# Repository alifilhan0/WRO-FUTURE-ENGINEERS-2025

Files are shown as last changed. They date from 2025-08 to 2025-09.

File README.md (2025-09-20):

# WRO Future Engineers 2025 – Team Barakah Brigade

>_"Machines may move, but minds make them meaningful."_

## I. The Chronicle Begins

Welcome to the official documentation of **Team Barakah Brigade**, proudly representing **Bangladesh** in the **WRO Future Engineers 2025** challenge. Our machine is not only a competition entry — it's a product of relentless design, weekend solder burns, deep debugging sessions, and the shared dream of building something that _knows what to do_ when left alone.

## II. The Machine: Purpose, Not Parts

Our vehicle is modular, intelligent, and ever-adapting. It uses a hybrid sensor approach to interpret its surroundings and make autonomous driving decisions in real-time — under the constraints and chaos of a real track.

### Core Concepts:

- **Multi-sensor Fusion**: For reliable perception, redundancy, and adaptation.
- **Real-time RTOS Decision Engine**: Powered by RT-Smart, giving predictable, scheduled execution for safety and speed. Providing an environment 
- **Microcontroller Offload Architecture**: Peripheral-heavy sensor reading offloaded to a C-programmed sensor hub board.
- **PWM-driven Motion**: Real-time speed and torque adjustments via software PWM on hardware-level pins.
- **Visual Processing Backbone**: Using the OV5647 camera as the main eye of the vehicle.
- **Machine Learning assisted motion**: Following the current trends, and picking up with the modern pace, ML assisted motion brings us the edge of driving and transportation technology with automation and reliablity

---
## Table of Contents

- [III. The Team](#iii-the-team)
- [IV. Mechanical Subsystem](#iv-mechanical-subsystem)
  - [Drive Train](#drive-train)
  - [Steering](#steering)
  - [Wheel Base](#wheel-base)
  - [Top and Base](#top-and-base)
  - [Camera Mount](#camera-mount)
- [V. Electrical Subsystem](#v-electrical-subsystem)
  - [Hardware Component Overview](#hardware-component-overview)
  - [CanMV K230 — The Heart of the Project That Brings Everything to Life](#canmv-k230--the-heart-of-the-project-that-brings-everything-to-life)
  - [K230 vs Raspberry Pi: Why We Preferred the K230](#k230-vs-raspberry-pi-why-we-preferred-the-k230)
  - [Custom PCBs](#custom-pcbs)
    - [(A) MCU Carrier Board](#a-mcu-carrier-board)
    - [(B) Power Distribution Board (PDB)](#b-power-distribution-board-pdb)
  - [Sensor Modules & Specifications](#sensor-modules--specifications)
    - [Reasoning behind choosing ToF Over Ultrasonic Sensors](#reasoning-behind-choosing-tof-over-ultrasonic-sensors)
    - [How we tackled problems while sensor calibration and debugging](#how-we-tackled-problems-while-sensor-calibration-and-debugging)
      - [Problem](#problem)
      - [Analysis](#analysis)
      - [Solution and Process](#solution-and-process)
    - [How it works at low level](#how-it-works-at-low-level)
    - [Other Active Modules](#other-active-modules)
      - [TCA9548A](#tca9548a)
      - [16GA 800RPM Motor](#16ga-800rpm-motor)
      - [JX-6221-MGI Servo](#jx-6221-mgi-servo)
- [VI. Software Subsystem](#vi-software-subsystem)
  - [Overview (Open Challenge)](#overview--open-challenge-)
    - [Approach](#approach)
    - [Data Collection](#data-collection)
    - [Model Training](#model-training)
    - [Conclusion](#conclusion)

## III. The Team

| Name | Role | Focus Areas | Picture |
|---|---|---|---|
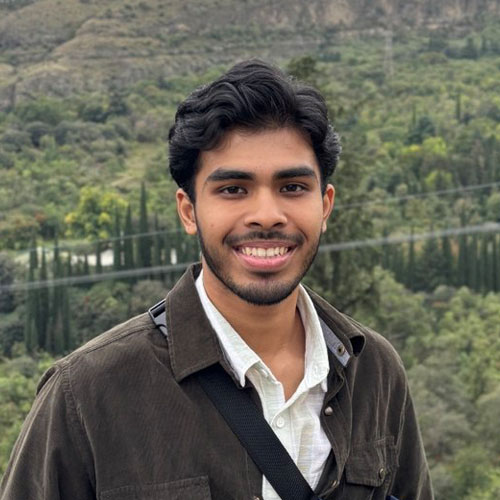
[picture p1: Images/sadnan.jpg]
| **Sadnan Adib Khan**  | Team Lead | Strategy, PCB design, Mechanical layout & Power Systems | |
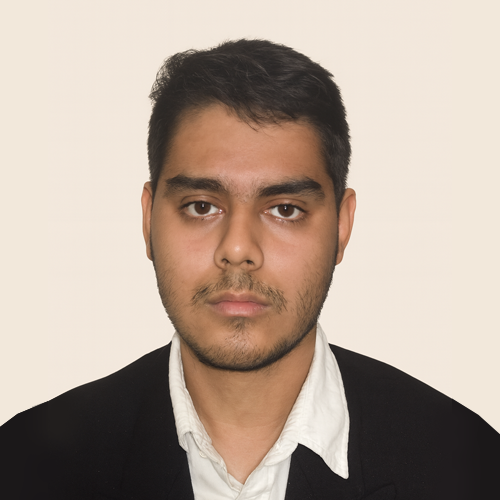
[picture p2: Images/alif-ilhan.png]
| **Alif Ilhan** | Embedded Systems | Firmware, Electrical design, Low Level-Sensor Integration and bringup |  |
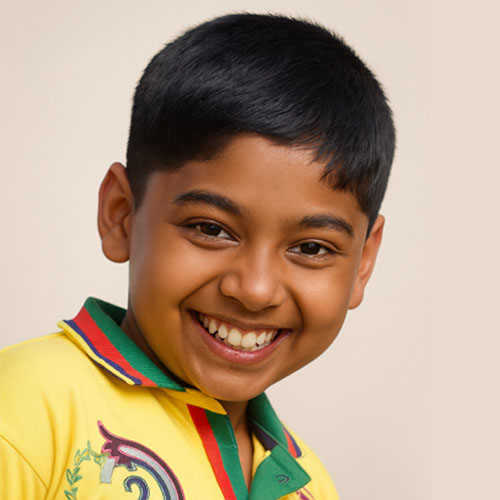
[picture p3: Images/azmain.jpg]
| **Azmain Inqiad Adib**| AI & Algorithm Architect | Machine Learning, Decision making, and camera vision processing |  |

---

# IV. Mechanical Subsystem
[Drive Train](#drive-train) · [Steering](#steering) · [Wheel Base](#wheel-base) · [Top and Base](#top-and-base) · [Camera Mount](#camera-mount)
---

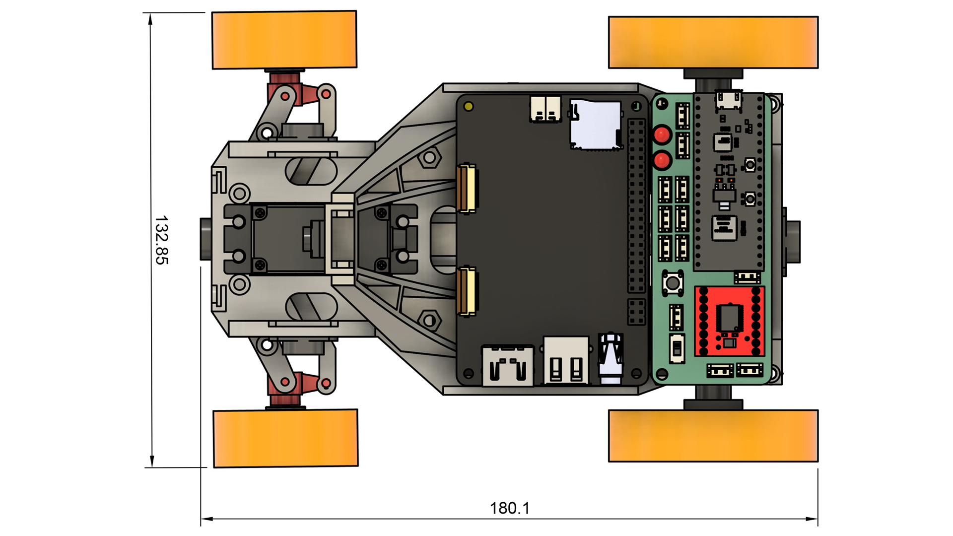
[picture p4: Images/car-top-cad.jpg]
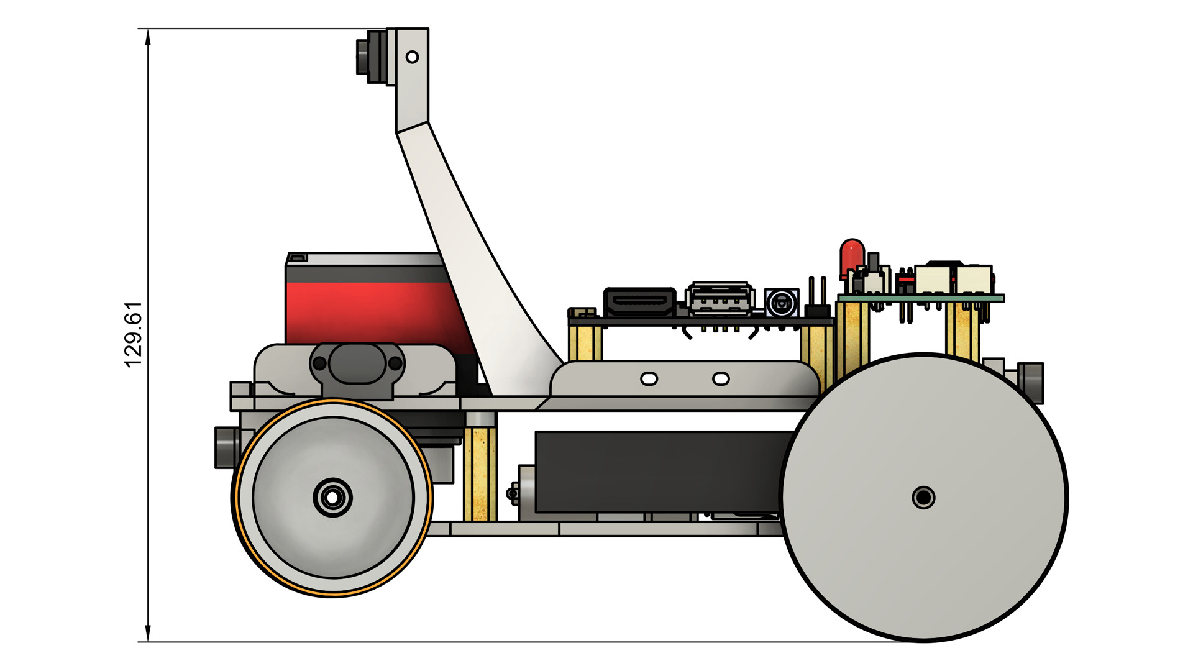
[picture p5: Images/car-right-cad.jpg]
|  | | 
| :--: | :--: |
| *Top* | *Right* |

Initially due to the lack of time and considering when we started working on the project we didn’t have much room to play around with the choice of components or mechanics. What we thought would work best theoretically wasn’t always the case, but we’re still satisfied with the hardware of the car but there’s much room for improvement. A few of the components we bought off the shelf which didn’t have CAD models available had to be modeled in CAD from precise measurements so that we could design around them efficiently.

## Drive Train

>Rear ***Open Differential*** from an RC car, ***16GA 800RPM motor*** 

We initially considered using a front-wheel drive with a front differential but chose a rear differential design for less complexity and better compatibility with our custom steering assembly. Instead of designing one from scratch, since 3D printed gears would wear out quickly and be bulkier, we opted for an off-the-shelf open differential from an RC car vendor. We went with a unit that used metal bevel gears, making it more reliable.

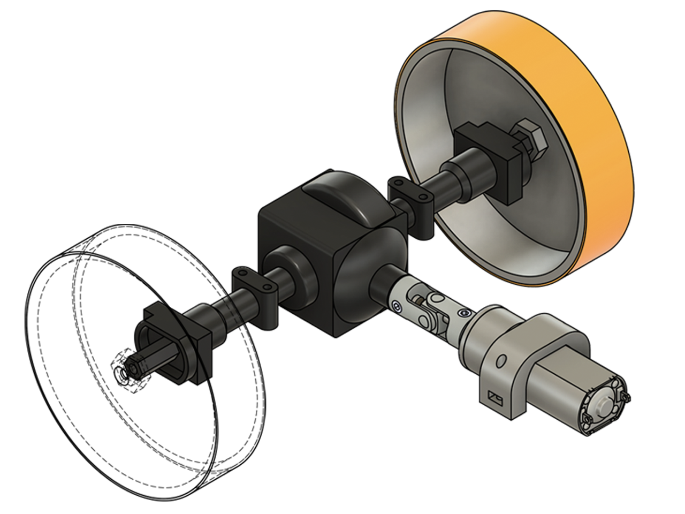
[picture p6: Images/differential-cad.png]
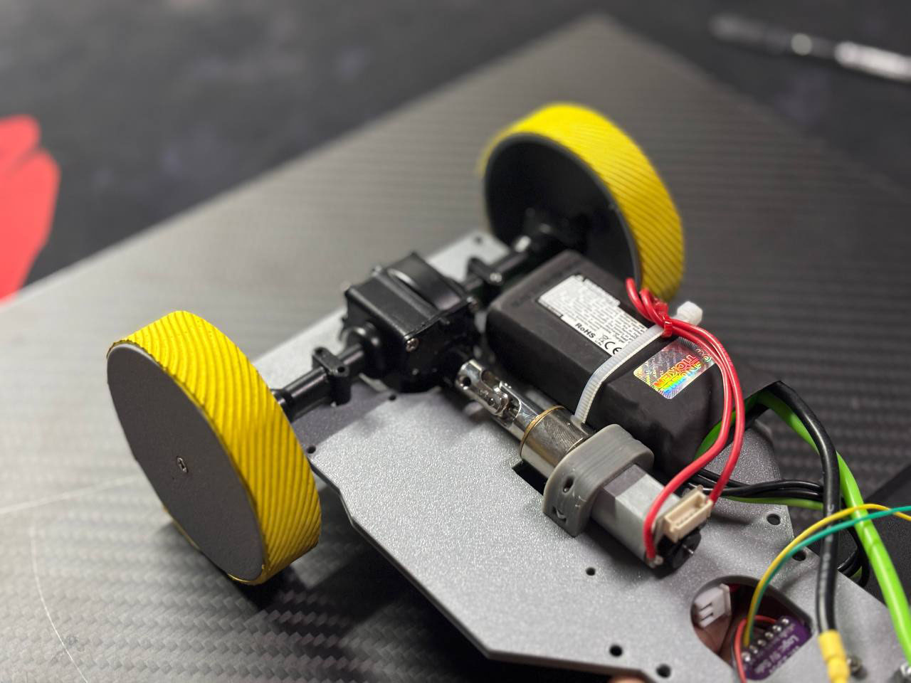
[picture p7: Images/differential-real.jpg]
|| 
| :--: | :--: | 
| CAD | After Assembly |

 The drawback was that we couldn’t adjust its width, so the overall width of the car was fixed by the differential.
Even though there wasn’t any documentation available, by testing we determined that this differential had a ***built-in gear reduction of 2.5:1*** which **cut our motor speed to less than half of its original output.** At one point, we even considered removing the differential altogether to prioritize speed, but the reliability it provided during cornering was unmatched, so we ultimately decided to keep it. How we worked on improving speed will be discussed in a later section.

The motor was fixed down to the base using a custom motor mount and ***M2 Hardware***, and connected to the differential through a ***universal coupler*** joint, which allowed for slight misalignments between the shafts and reduced the risk of stress or bending.

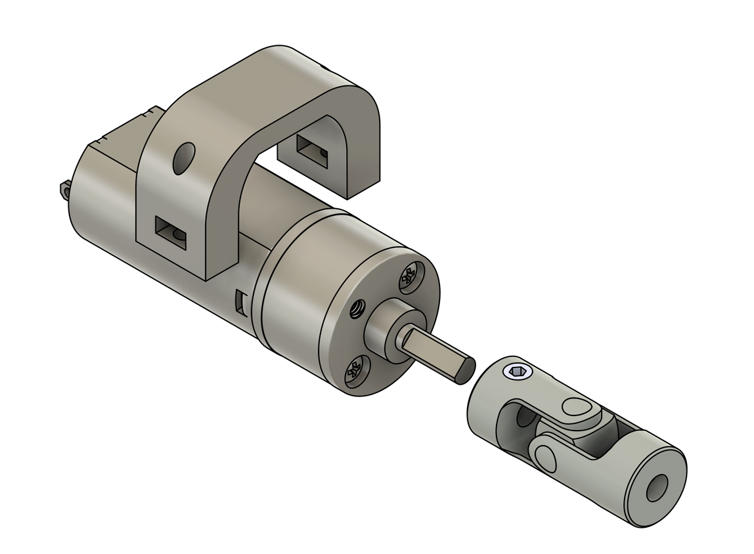
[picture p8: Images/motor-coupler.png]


### Potential Upgrades
- Use a LEGO differential due to it's compact nature (speculation)
- Shift to a BLDC motor or a custom gearbox 

## Steering
A ***modified version of the Ackermann steering*** that provides ***upto 64°*** of rotation from the zero position

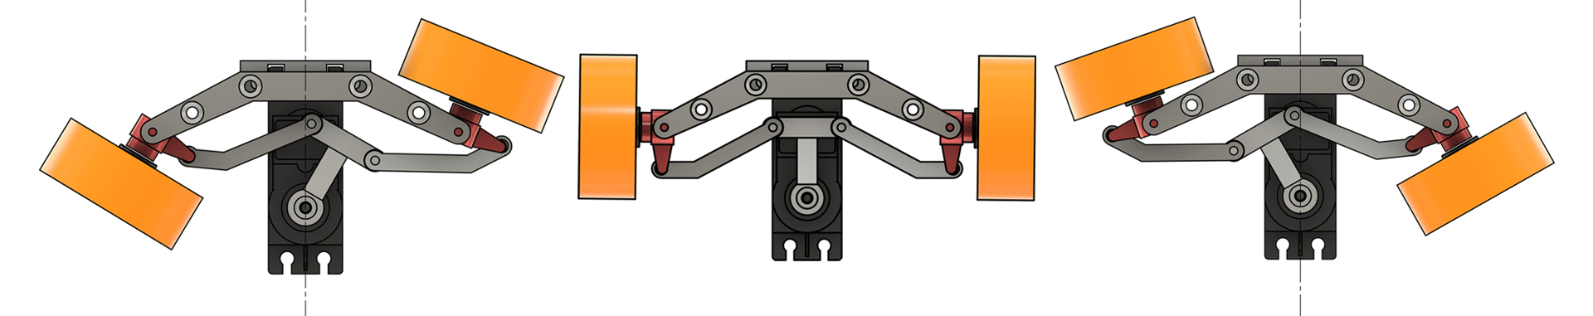
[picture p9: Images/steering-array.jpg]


Our main goal was to make an Ackermann steering system with tighter turning ability than standard ones. But we soon found out that the metal steering knuckles we had, due to their fixed geometry, did not allow us to achieve a positive Ackermann percentage. Although true Ackermann steering would have reduced tire slip during tight turns, the geometry of our available knuckles limited us to a near ***parallel*** or rather an unintended ***Anti-Ackermann*** setup.

This compromise was acceptable for us since the car primarily operates at moderate speeds on smooth surfaces, where tire scrub has minimal impact. We did not want to 3D print the steering knuckle, as it had to bear most of the lateral loads during the tighter turns, so we decided to design around it. This wasn’t by choice, but a compromise we had to make to work with the hardware available.

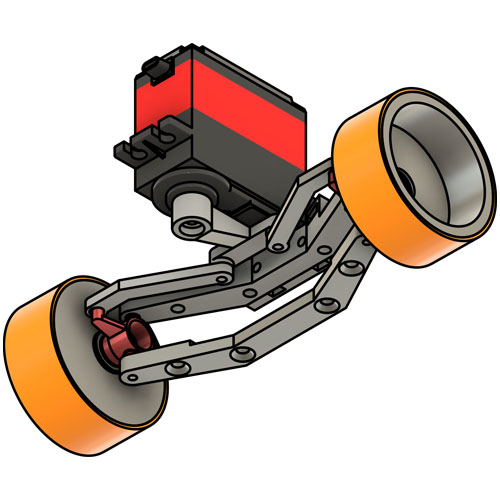
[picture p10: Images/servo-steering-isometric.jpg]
| | | 
| :--: | :--: |
| GIF | Isometric View |

We took an approach to design most of the joints for the steering assembly using a **ball-socket mechanism**, which gave us some room for error and tolerance while designing. We had to print this joint multiple times to make sure the fit had minimal play but still rotated freely. A custom servo horn then allowed us to connect the tie rods and move both sides symmetrically.

### Potential Upgrades
- Using custom steering knuckles
- Switch to off the shelf ball socket joints
- Design a better mounting system

## Wheel Base
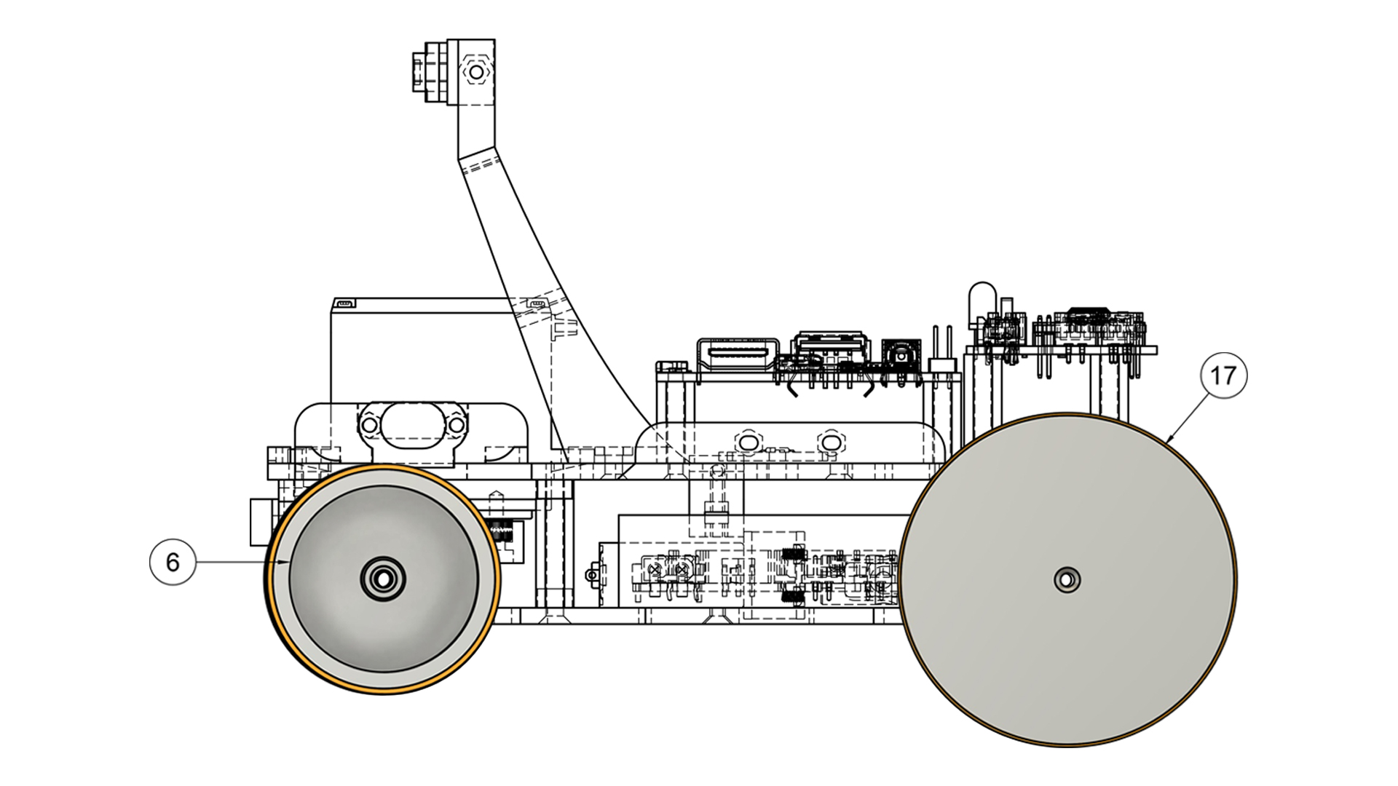
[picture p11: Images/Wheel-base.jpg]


It’s apparent from the design that the front and rear wheels have different diameters. This was intentional to recover some of the speed lost to the differential’s reduction. We kept the front wheels smaller to preserve steering clearance and a large steering angle.

> **Front wheel (6)** Diameter: ***40mm*** <br>
> **Rear wheel (17)** Diameter: ***60mm***

| Formula | Where |
|---|---|
| $v = r \omega$ | $v$ = linear velocity <br> $r$ = radius <br> $\omega$ = angular velocity |

Very self explanotory how ***increasing the wheel radius ($r$) increased the car’s speed ($v$).*** The drawback was that, given the relatively low-torque motor, the car sometimes struggled to pick up speed from a stall position, especially considering its weight. However, this was not a major issue in practice, since during runs the car mostly operates at a near-constant velocity once in motion.

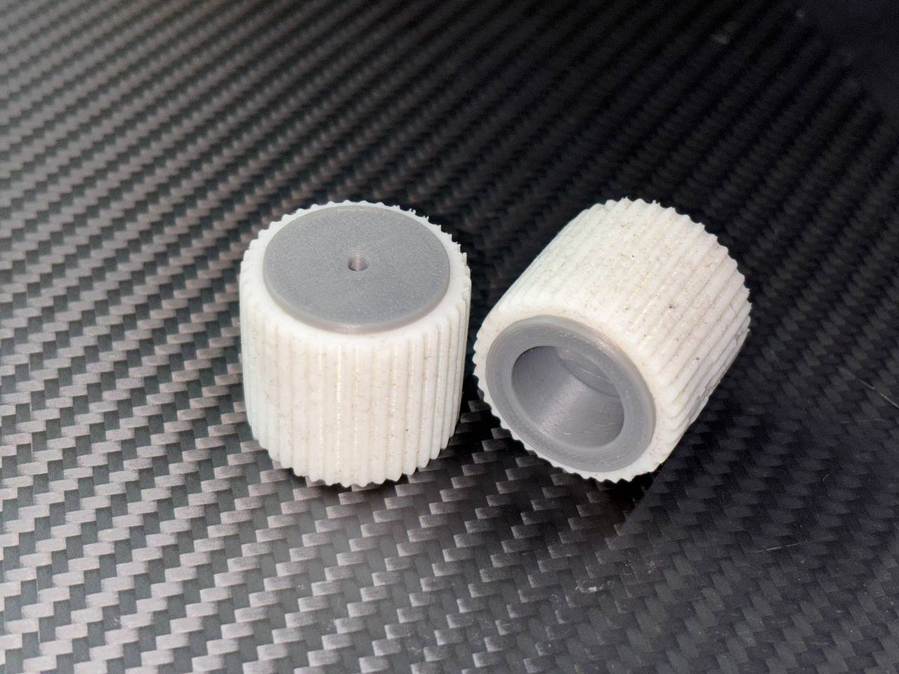
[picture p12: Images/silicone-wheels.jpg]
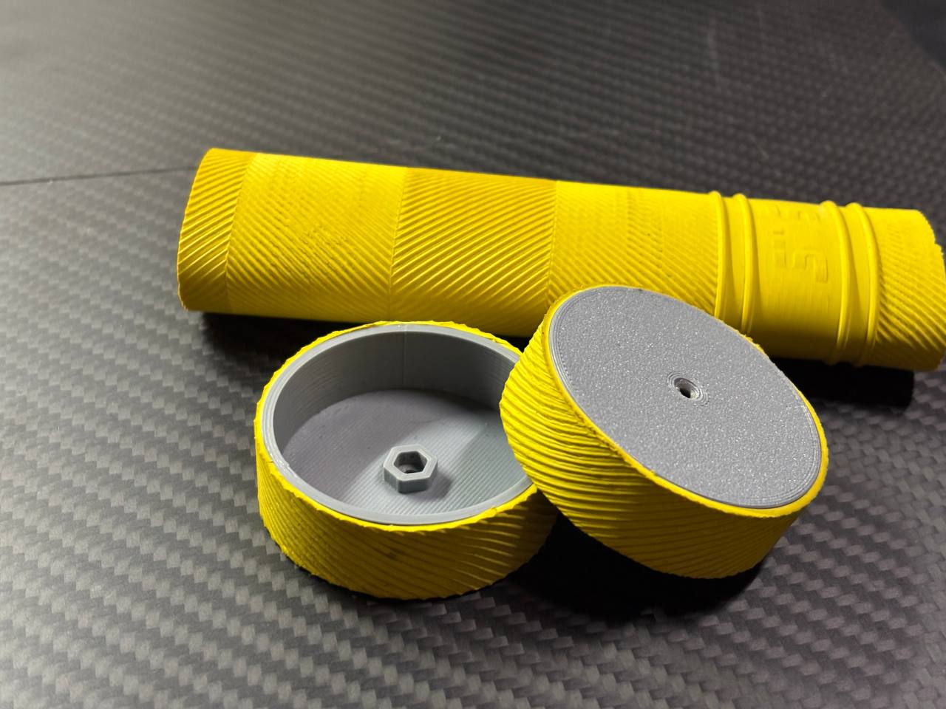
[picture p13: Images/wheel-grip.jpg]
|  |  | 
| :--: | :--: |
| Silicone wheel covers used in a previous project | Cricket Bat - Wheel Grips |

As for the wheels Grips, we had experience making silicone wheels by casting them in 3D printed molds, but it was difficult to achieve thin and uniform silicone covers. Due to time constraints, we decided to try what was already being used in the local RC car and line-follower robot community — ***Cricket bat grips***. To our surprise, the material worked perfectly. Our silicone covers tended to attract a lot of dust and quickly lose grip even on relatively clean surfaces, but the rubber grip material provided consistent traction and much better reliability.

### Potential Upgrades
- Having a more uniform diameter between the rear and front wheels would have prevented several issues we later faced—such as needing to account for the tilt when adjusting the TOF sensors. This issue was eventually solved and will be discussed in a later section.

## Top and Base

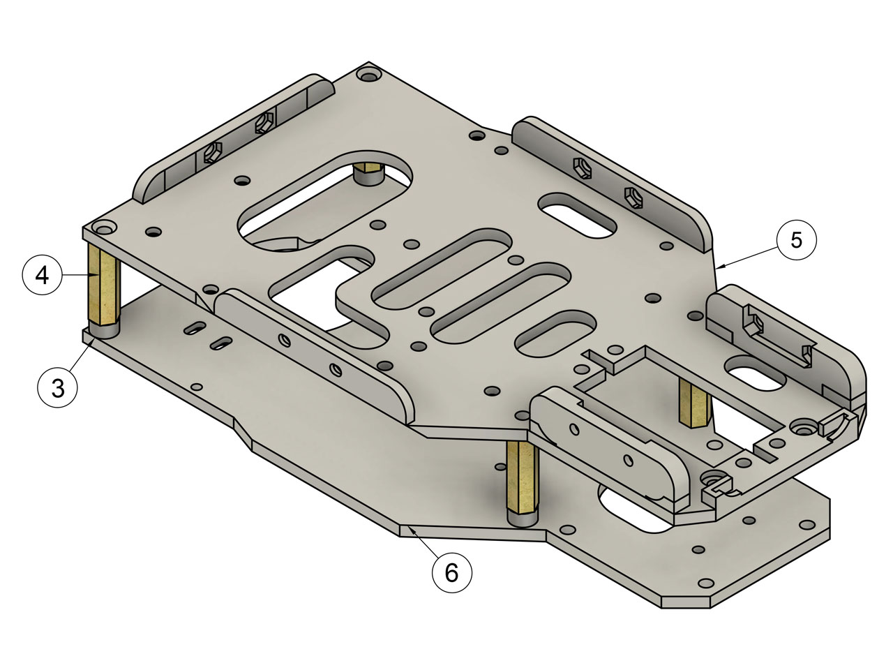
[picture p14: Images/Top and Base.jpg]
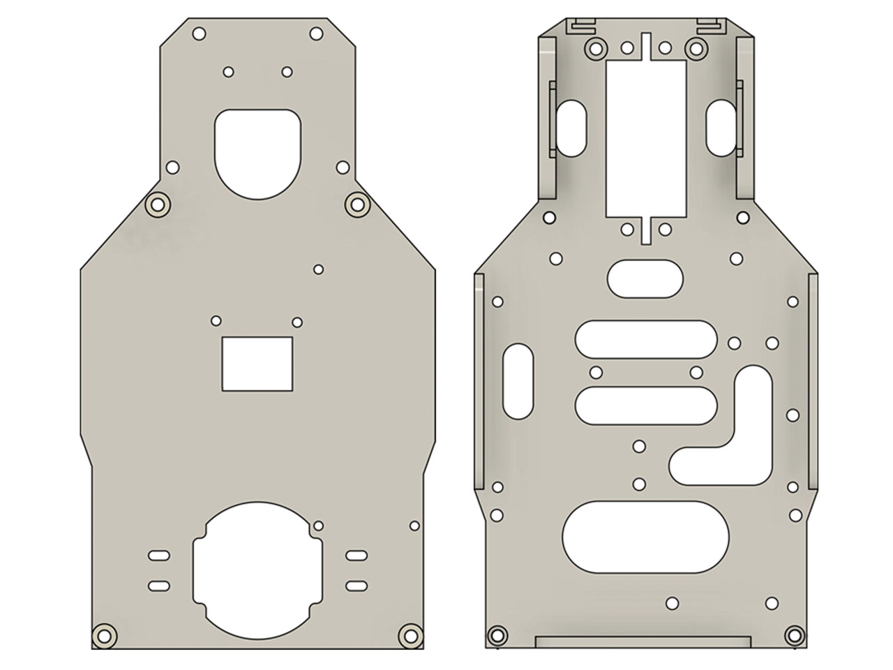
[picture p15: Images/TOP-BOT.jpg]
|  |  | 
| :--: | :--: |

The entire structure of the **top (5)** and the **base (6)** was edited dozens of times, so the current iteration is somewhat patched together as we built on top of the original design. It went through multiple sensor mount shifts and other modifications. Larger cutouts were kept strategically for minimal cable clutter, easier routing, and to reduce overall weight. The **top (5)** and the **base (6)** are connected using ***20 mm brass hex spacers (4)***, with additional ***3D printed spacers (3)*** used alongside the brass hardware to reach the required height. The mounts for the TOF sensors are built directly into the **top (5)** while this left less room for later adjustments, the layout was finalized after extensive iterations and worked reliably for our needs.

### Potential Upgrades
- There is still a lot of room for improvement. After finalizing the design, this should be remade from scratch while taking inspiration from the current version. The current iteration contains excess geometry and structural clutter. A future redesign from scratch, while reflecting on lessons from this version, would allow for a cleaner and more efficient structure.

## Camera Mount

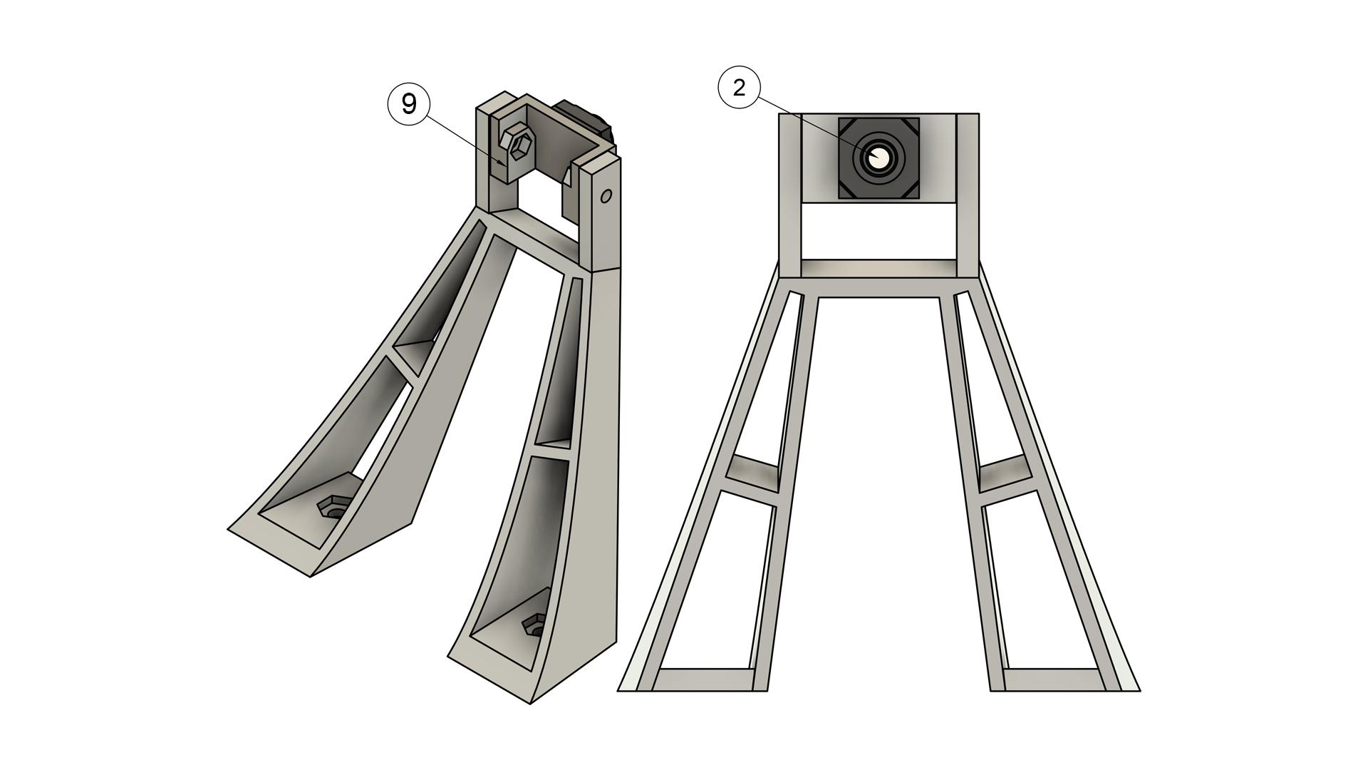
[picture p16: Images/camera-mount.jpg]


We did not follow any strict constraints or dimensions while designing the camera mount. The curved shape of the structure was inspired by the **horn of a horned beetle**, while the main focus was on making it sturdy and incorporating a **pivotable(9)** joint for the **camera(2).**

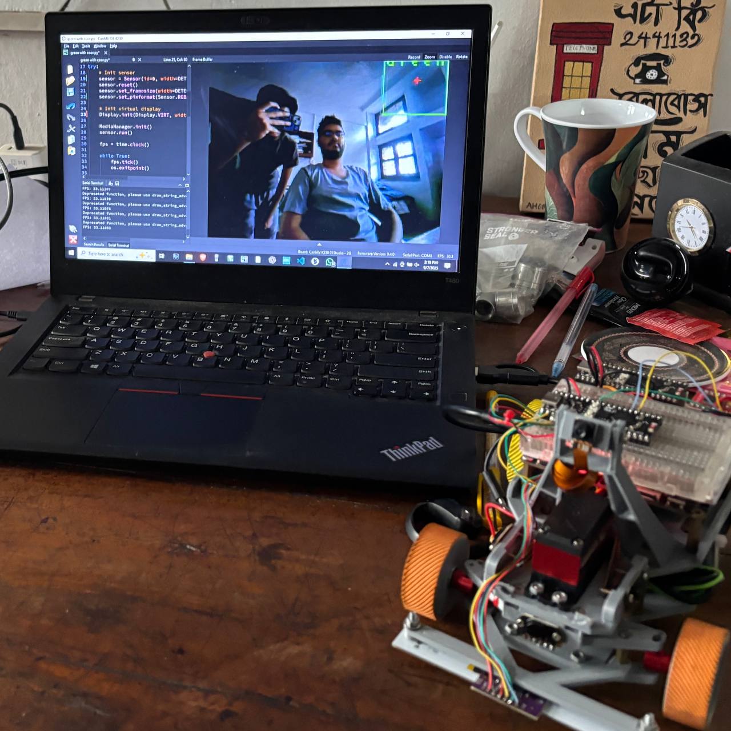
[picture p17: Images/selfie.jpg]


### Potential Upgrades
- Change the mounting system that attaches to the top of the car.
- Upgrade the camera mount and pivot system.
---

# V. Electrical Subsystem

[Hardware Component Overview](#hardware-component-overview) · [CanMV K230](#canmv-k230--the-heart-of-the-project-that-brings-everything-to-life) · [K230 vs Raspberry Pi](#k230-vs-raspberry-pi-why-we-preferred-the-k230) · [Custom PCBs](#custom-pcbs) · [Sensor Modules](#sensor-modules--specifications) · [Other Active Modules](#other-active-modules)
---

The Electrical Subsystem includes all components ranging from sensors to processing boards, along with the supporting electronics used in the build. Issues faced during development and their solutions are discussed in a separate section.

### Hardware Component Overview

| Module | Description |
|---|---|
| **Mainboard** | `01Studios CanMV K230` powered by kendryte chips for most of the heavylifting, running Python, Machine learning models for high-level logic |
| **Sensor Hub** | A custom PCB housing the `ESP32-S3-Pico` microcontroller running ESP-IDF V5.5.1 managing all the sensors and UART communication with mainboard |
| **Drive System** | Drive control is handled by the `TB6612FNG` motor driver, using PWM to drive the 16GA motor. |
| **Power Delivery**  | Power is managed through a custom distribution board that delivers clean and regulated ***3.3V, 5V,*** and ***12V*** rails across the electrical system. |
| **Steering System** | The custom Steering Assembly is driven by the well-regarded `JX PDI-6221MG` servo. |

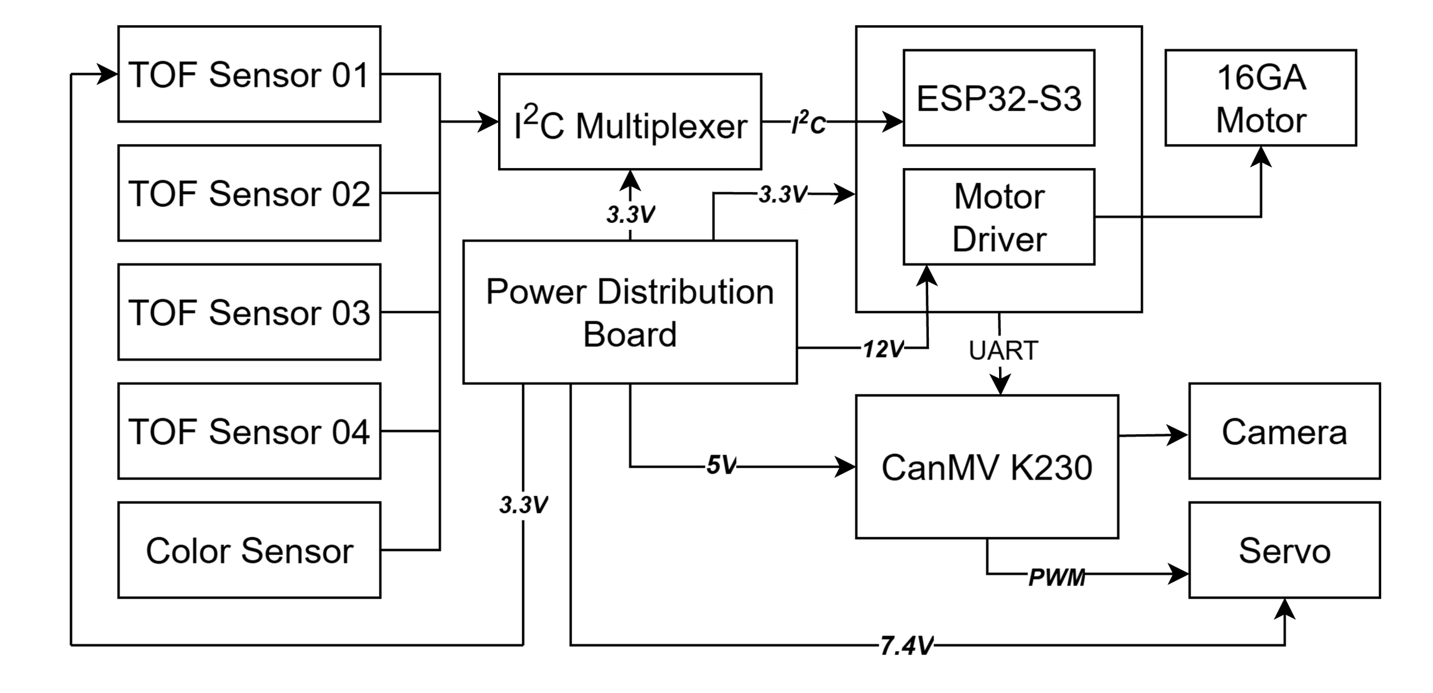
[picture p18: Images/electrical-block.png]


## CanMV K230 — The Heart of the Project That Brings Everything to Life

Our project requires vision processing, Deep Learning capabilities, and a rich programming environment for seamless operation of the car. `Raspberry Pi` was an option, however, its lack of dedicated hardware acceleration for AI and deep learning was a sore thumb. After searching around the market for options like `Jetson Nano(🤑)`, we found this `01Studios CanMV K230 board` which had dedicated hardware accelerators for AI and vision, and also had a rich programming interface through CanMV IDE from the vendor, and all of that in a very affordable price. And on top of that the documentation was very elaborate and helped us get started very quickly.

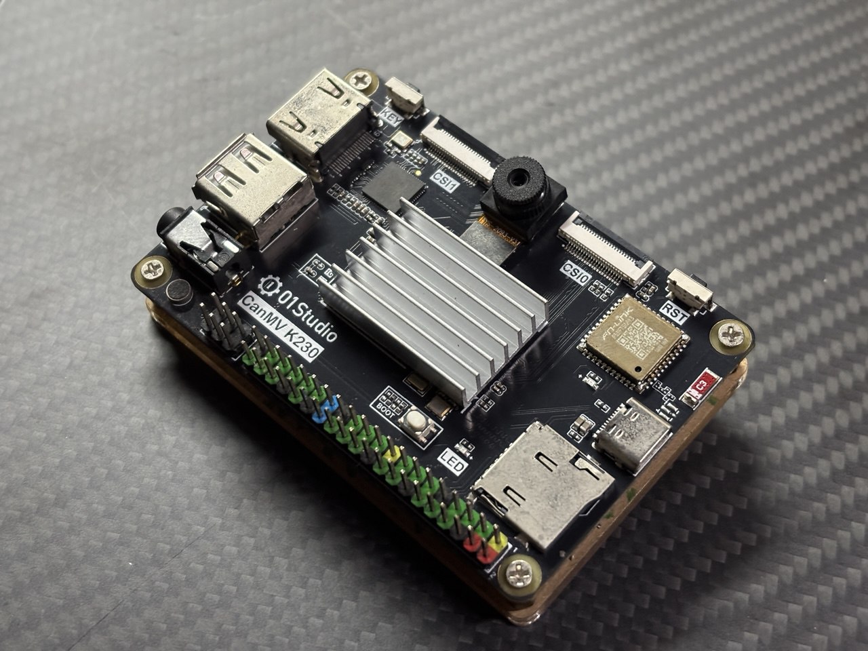
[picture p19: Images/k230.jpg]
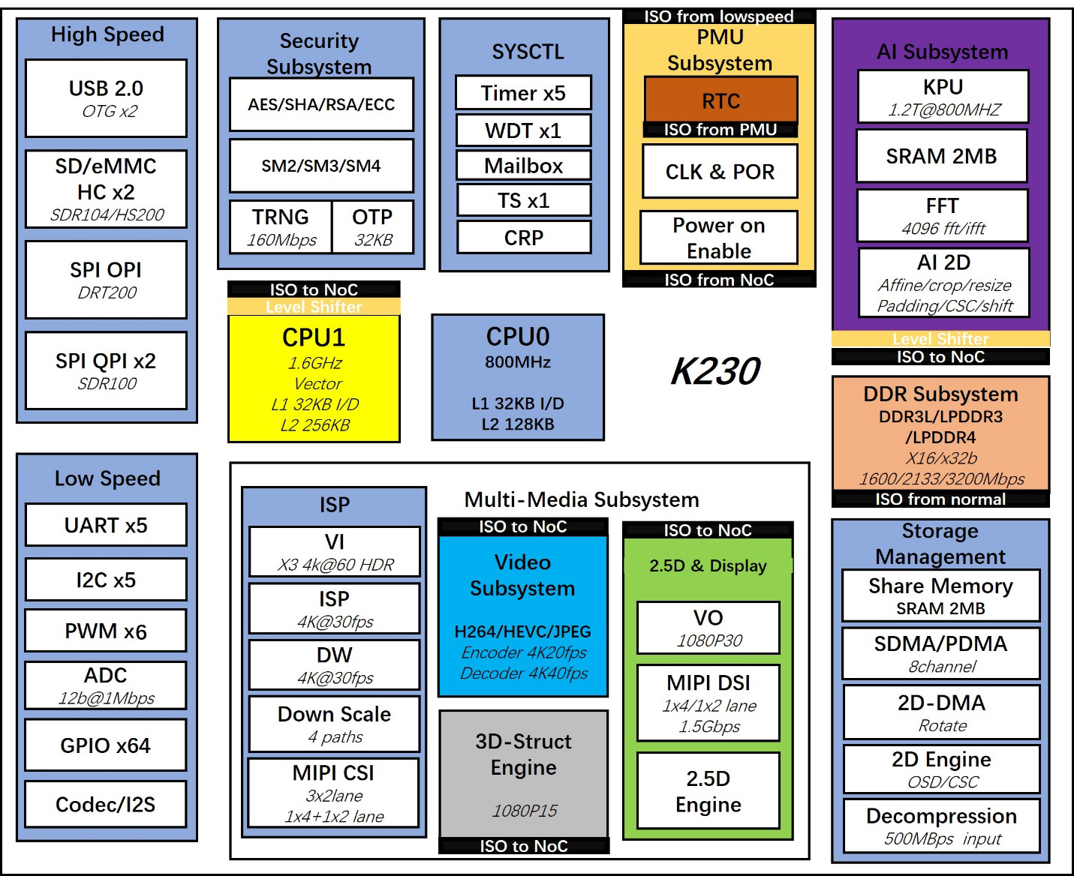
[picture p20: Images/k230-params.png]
 |  | 
| :--: | :--: | 

Setting up the board was very simple. We only had to flash the vendor supplied image to an sdcard with `rufus.exe` and put the card into the sdcard slot of the board.
Full elaborate documentation and resources from vendor is available [here](https://wiki.01studio.cc/en/docs/category/canmv-k230套件介绍)

| Specification | Details |
|---|---|
| Name | 01Studios Kendryte K230 Development Board |
| RAM | 2GB LPDDR4 |
| AI Acceleration  | Kendryte’s unique `KPU` (Kendryte Processing Unit) |
| Ports | 1x USB-A, 1x USB-C (power & programming), 1x HDMI, 1x SDCard slot |
| GPIO | 40, compatible with Raspberry Pi |
| TDP | 20W max |
| Camera | Upto 3 camera interfaces |

## K230 vs Raspberry Pi: Why We Preferred the K230
> Simple reason, The **KPU 🤡**

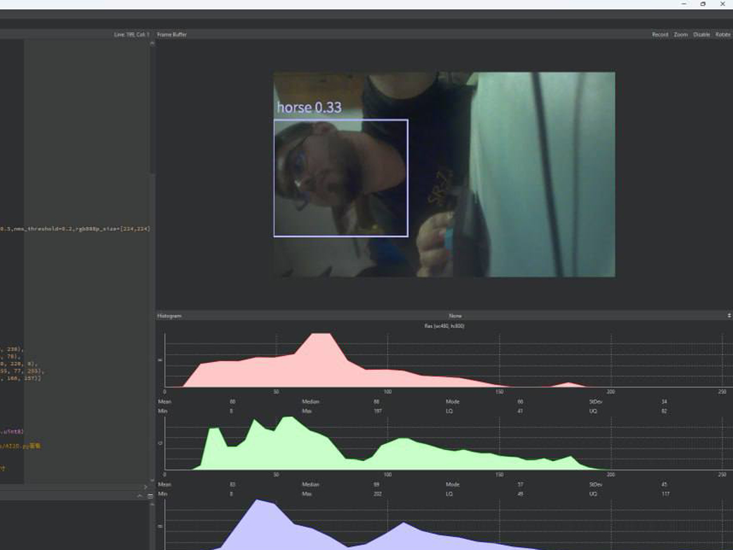
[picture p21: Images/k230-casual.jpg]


The ``Raspberry Pi`` as said before lacks a dedicated AI Accelerator, which has an option to be separately bought but that raises both design firmware bringup complexity. Also the added ``70TOPs`` performance was an overpriced overkill so, we chose the K230. Its KPU gives an equivalent to ``6TOPS`` NPU performance, which is perfect for ours and the vast majority of AI enabled embedded projects.

| Specification | Details |
|---|---|
| Subsystem | KPU (Kendryte Processing Unit) |
| Data Types | Supports INT8 and INT16 |
| Weight Optimization | Weight sparse compression |
| Performance (Typical) | ResNet-50 ≥ 85 fps @ INT8<br>MobileNet_v2 ≥ 670 fps @ INT8<br>YOLOv5s ≥ 38 fps @ INT8 |
| Framework Support | TensorFlow, PyTorch, TFLite, PaddlePaddle, ONNX |
| Toolchain & Profiling | Quantization toolchain, profiling tools |
| Quantization Accuracy Loss  | < 1% |

## Custom PCBs
To keep the vehicle clutter-free and make debugging easier, we resorted to custom PCBs which also allowed for more reliable connections. These were designed in KiCad and later CNC milled. All of them were single layered boards for the ease of manufacturing.
>- **(A)** Microcontroller Carrier Board Housing the ESP32-S3-Pico and the motor Driver.
>- **(B)**  Power Distribution Board with regulated ***3.3V, 5V,*** and ***12V*** supplies.

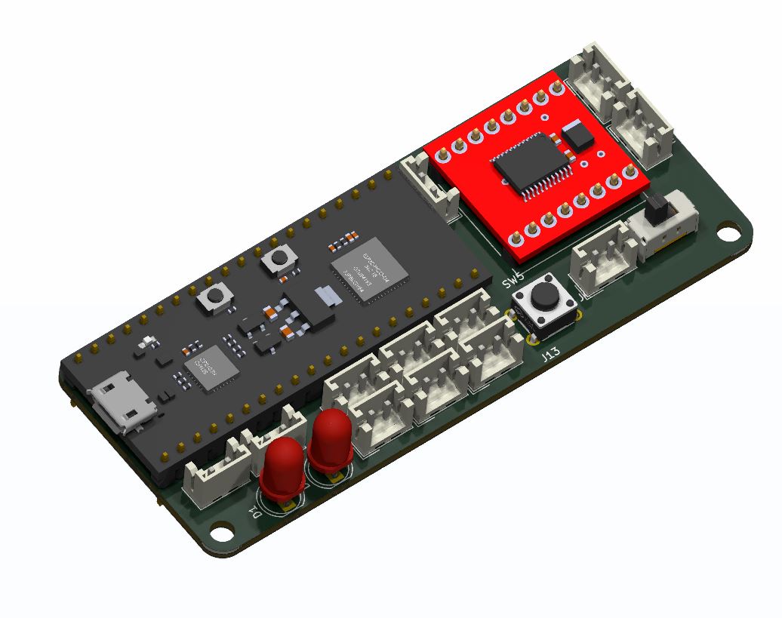
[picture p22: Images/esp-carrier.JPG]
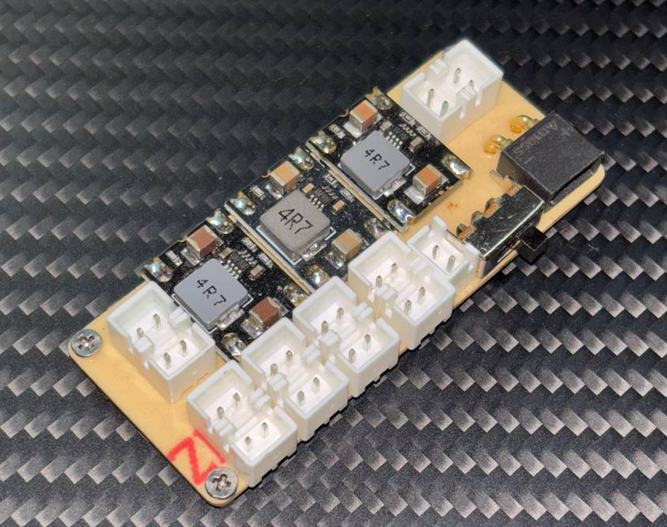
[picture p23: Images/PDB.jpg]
|  |  | 
| :--: | :--: |
| (A) MCU Carrier Board | (B) PDB |
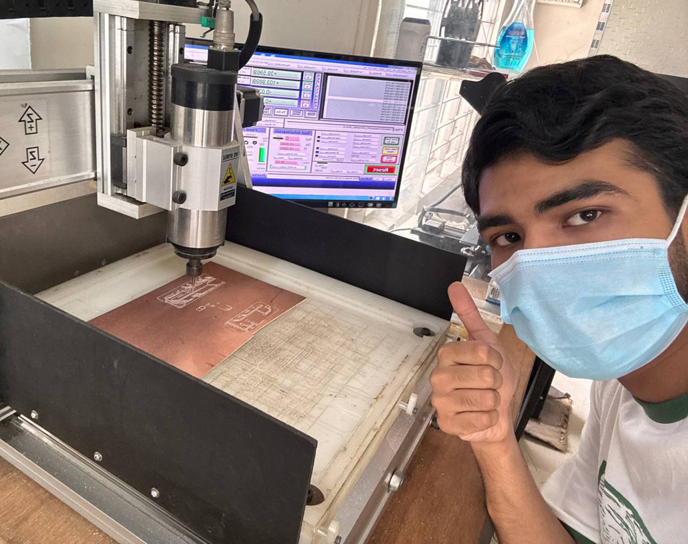
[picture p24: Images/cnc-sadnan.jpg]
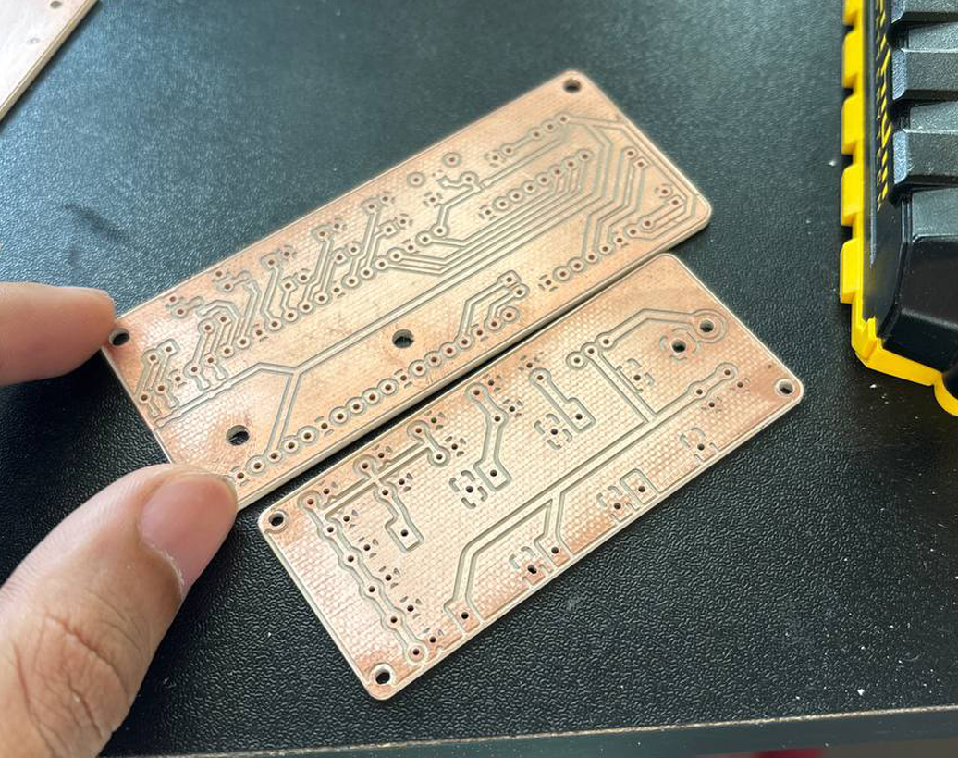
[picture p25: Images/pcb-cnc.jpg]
|  |  | 
| Things that make a man happy | Snacks |

### (A) MCU Carrier Board

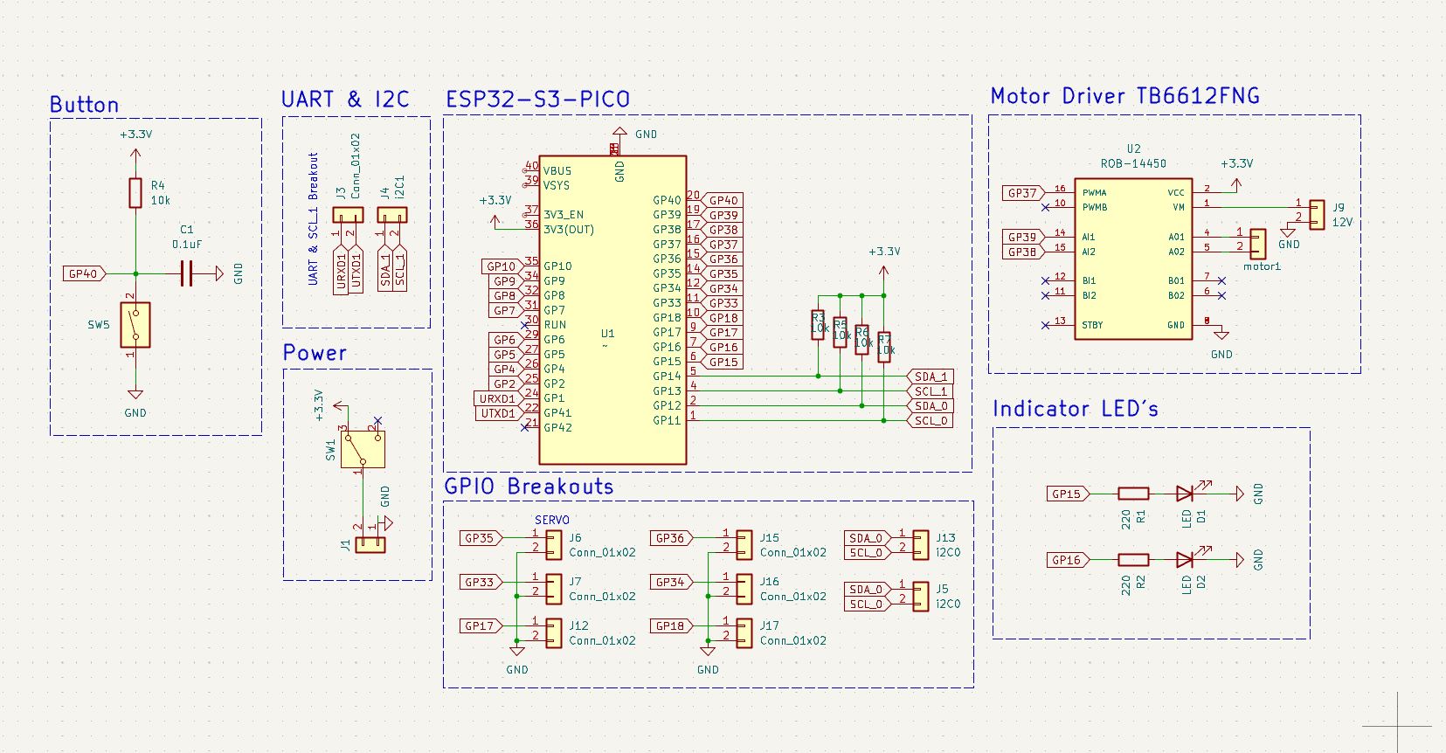
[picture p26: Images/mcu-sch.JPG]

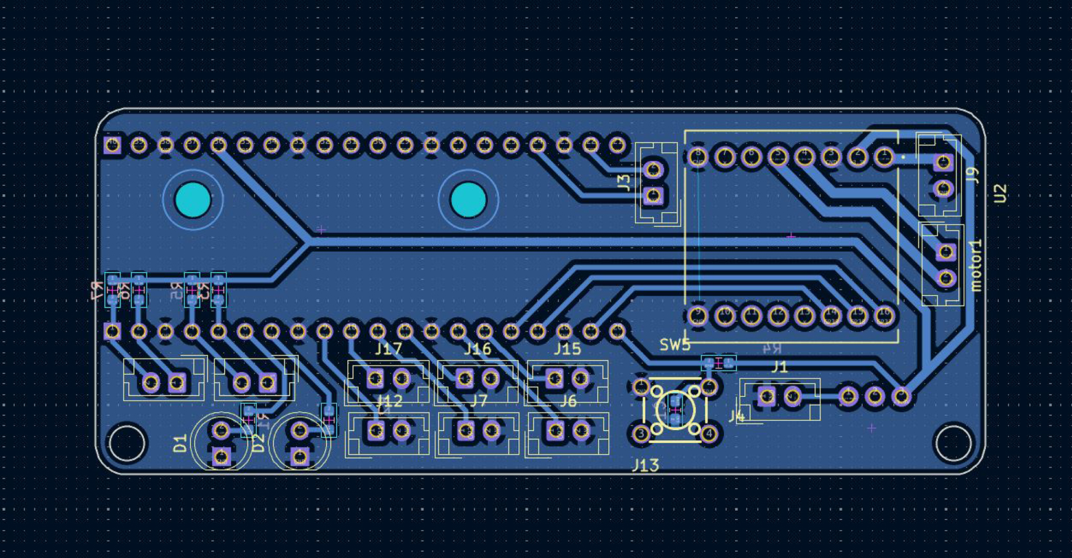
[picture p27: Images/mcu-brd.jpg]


### (B) Power Distribution Board (PDB)
Instead of designing our own voltage regulators, we used **fixed-voltage buck converters** for convenience. The main power comes from a ***12V lithium-polymer battery*** and is distributed through multiple **JST headers**, They were chosen to maximize modularity, flexibility, and ease of repair.

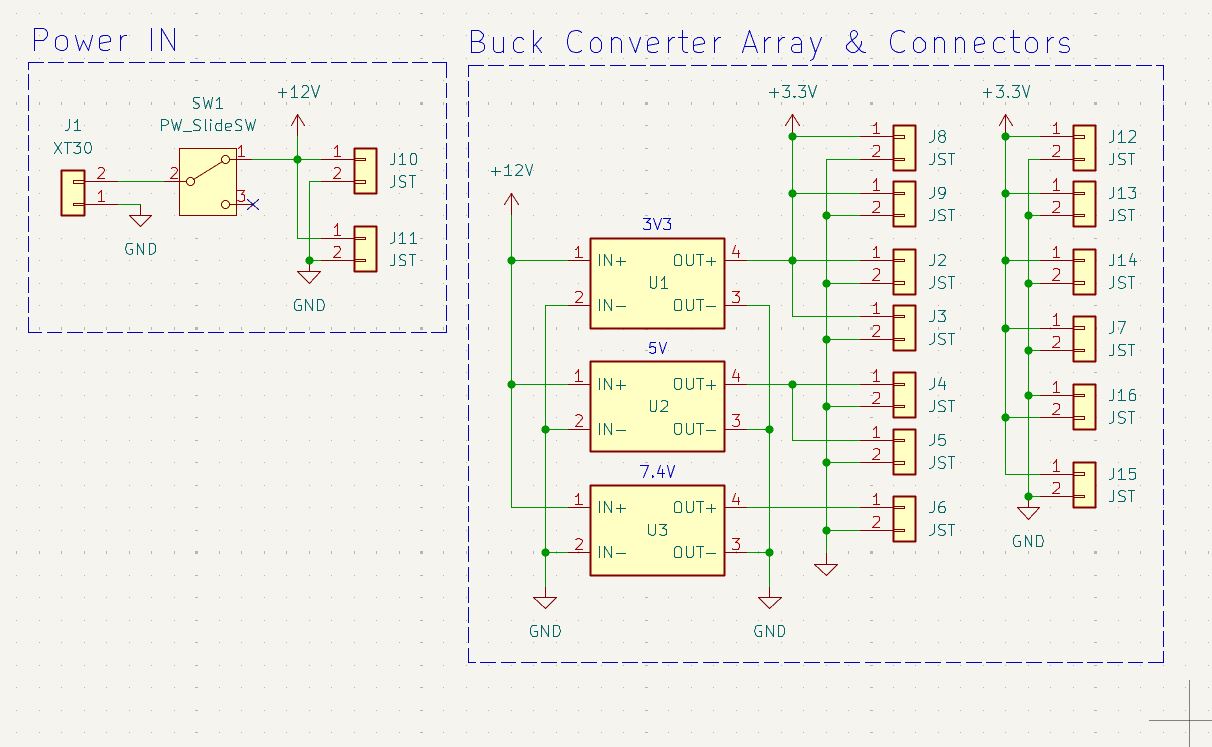
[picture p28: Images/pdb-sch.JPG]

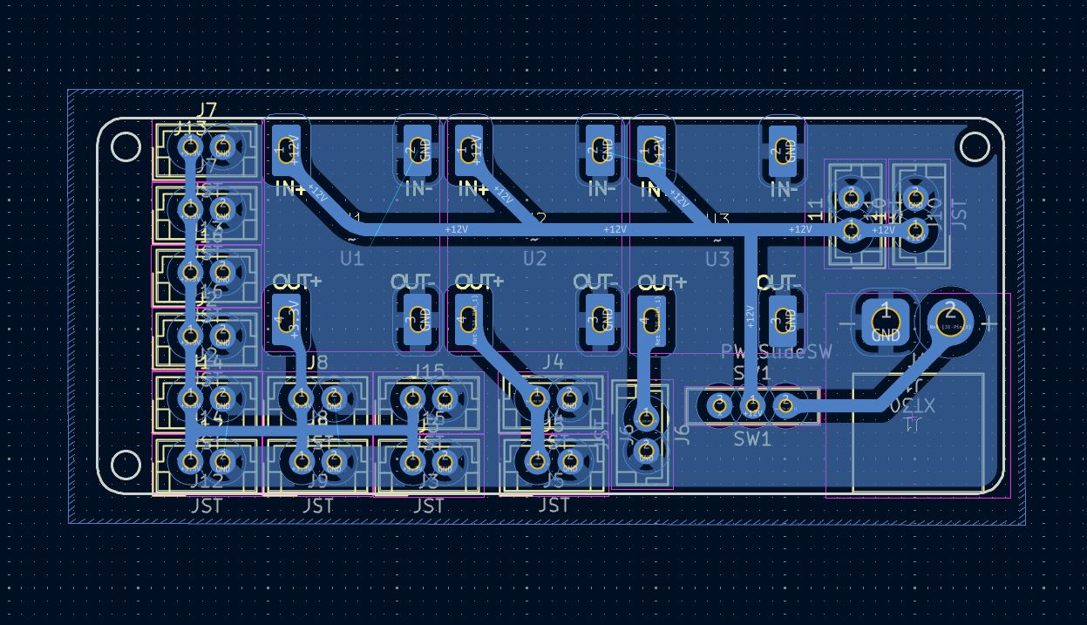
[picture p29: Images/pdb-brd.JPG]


## Sensor Modules & specifications

| Name | Type | Communication | Range | Purpose | Picture |
|---|---|---|---|---|---|
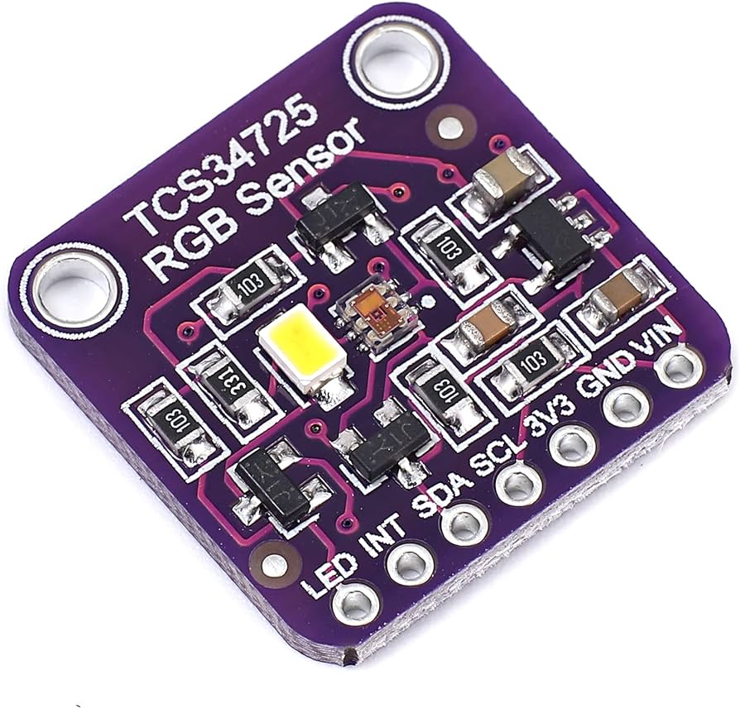
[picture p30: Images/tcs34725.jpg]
| TCS34725 | RGB color sensor  | I2C | – | Calculate the amount of laps taken. | |
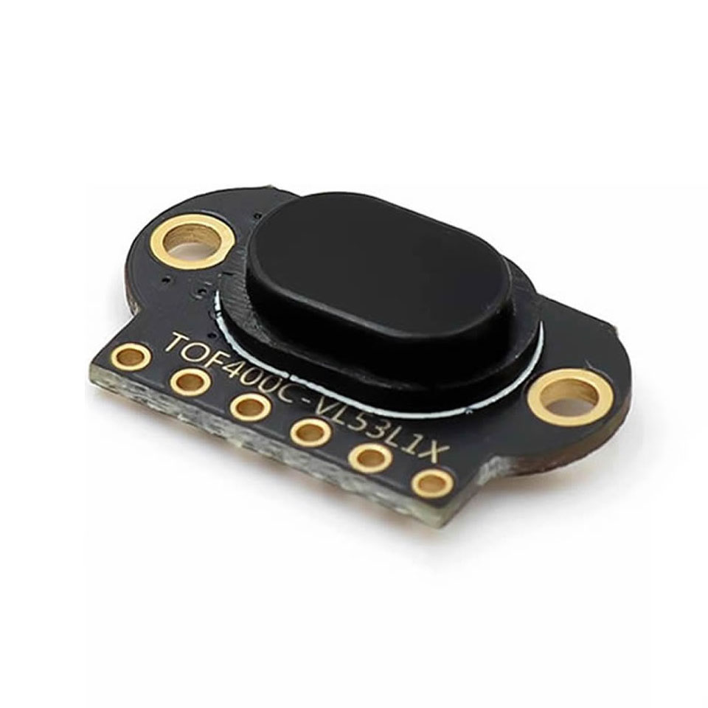
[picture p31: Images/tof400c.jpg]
| VL53L1X  | ToF sensor | I2C | 4–400cm | Calculate distance of the closest obstruction. Can sample @ 50 Hz, suitable for high-velocity operation without loss of accuracy. |    |
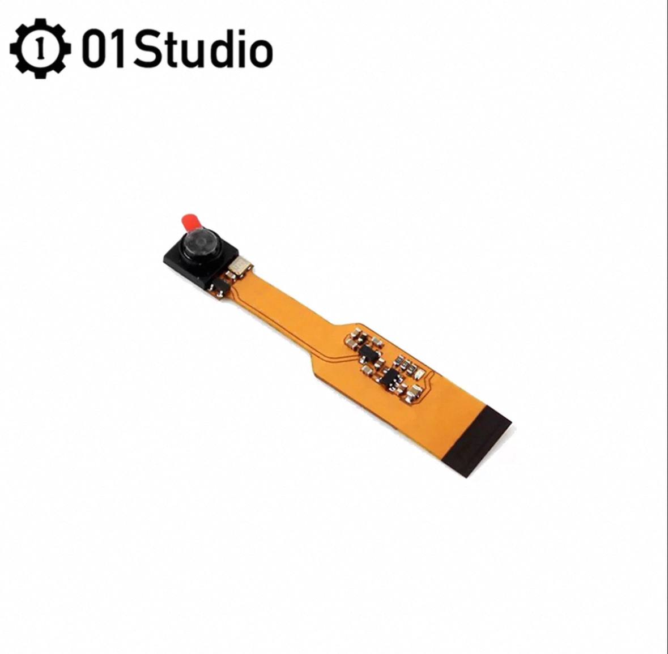
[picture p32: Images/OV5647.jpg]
| OV5647 | CSI camera module | MIPI CSI | 120° | Main vision of the car system. Detects objects and artifacts, sending data to be processed. |  |

### Reasoning behind choosing ToF Over Ultrasonic Sensors

In all honesty, ultrasonic sensors were a very good alternative — in some cases, maybe even better than our ToF sensors. However, we wanted full control over how our car perceived its environment, which meant having full control over the sensors we were using. With ultrasonics, there was no way to visualize or modify the region of interest, and we had little control over the spread of the sound waves.

With ToF sensors, however, we discovered a simple but ingenious solution (discussed here) that became a real game changer. On top of that, we had much more low-level control thanks to the availability of the [official API manual](https://www.st.com/resource/en/user_manual/um2356-vl53l1x-api-user-manual-stmicroelectronics.pdf)

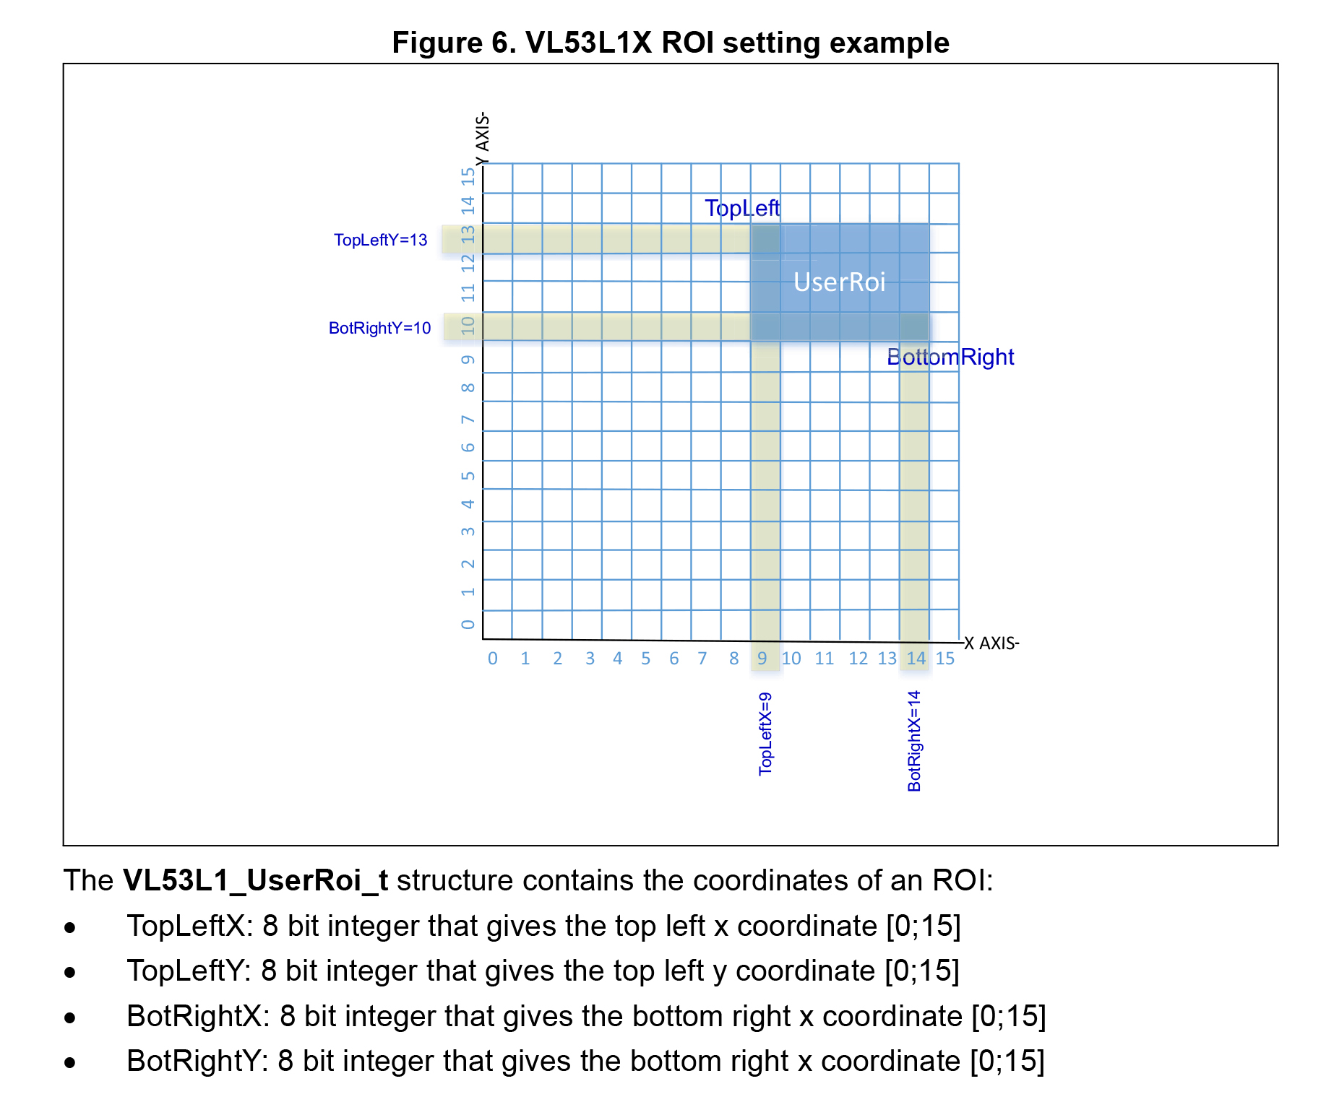
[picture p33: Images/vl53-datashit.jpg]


In our case, the ability to configure the ***ROI (Region of Interest)*** played a significant role. By narrowing the ROI, the sensor focused on the track directly ahead, reducing noise from peripheral objects, while widening it allowed for broader awareness when needed. Since the walls were painted matte black, **a smaller ROI produced a more concentrated beam that returned more photons, helping the readings remain accurate even on such a low-reflectivity surface.**

### How we tackled problems while sensor calibration and debugging 
#### Problem:
ToF sensor positioning and tilt angles were initially misaligned, resulting in unstable and incorrect distance readings during test runs. The libraries we used were forked from ESP-IDF-LIB repos and adapted for the WRO track, but this meant that both hardware and software calibration was needed. This consumed a significant amount of testing time.



#### Analysis:
ToF sensors use infrared (IR) light to measure proximity, and calibration is not straightforward. Although ROI (Region of Interest) settings can be tuned in firmware, they don’t solve the problem of physical misalignment. If the sensor was tilted incorrectly, we would get unreliable values or sometimes no readings at all. At first, we tried multiple tilt angles and calibration combinations, but this trial-and-error approach was time-consuming.

#### Solution and Process

Since the sensors work by emitting IR, we needed to visualize where the IR light was reflecting. CCD-based webcams are sensitive to IR, so we modified one by removing its **IR-Cutoff Filer**. 



This allowed us to directly observe the ToF IR emission patterns and how they reflected off surfaces. Using this method, we could finally align the sensors accurately with the track.

### How it works at low level

Our initial plan to keep the system as a single processing unit was discarded in favor of a sub-controller approach. Instead of spending CPU cycles on polling, converting, and calculating sensor data, the `ESP32-S3-Pico dev boards` were tasked with handling sensor input. 

The sensors were initialized and communicated with through **I2C**. `VL53L1X` ToF sensors were chosen as the primary sensors due to their longer range, higher sensitivity, and quick responsiveness. Although their addresses can be changed using XSHUT pins in case of address conflicts, we opted to use a `TPCA9548A I2C multiplexer` to reduce design complexity.

Data from the ToF sensors was gathered in a continuous looping task using the rich features of the **ESP-IDF v5.5.1** framework for the microcontroller. The sensor data was stored in a global variable, ready to be transferred to the main board on demand, as shown in the following code:

```c
/* Initialise the sensors */
void app_main()
{
    ESP_ERROR_CHECK(i2cdev_init());
    tca9548_init_desc(&i2c_switch, 0x70, 0, CONFIG_I2C_MASTER_SDA, CONFIG_I2C_MASTER_SCL);

    const uint8_t channels[4] = {0,4,3,5};
    for(int i=0;i<4;i++){
        tca9548_set_channels(&i2c_switch, BIT(channels[i]));
        vl53l1x_arr[i] = vl53l1x_config(0, CONFIG_I2C_MASTER_SCL, CONFIG_I2C_MASTER_SDA, -1, 0x29, 0);
    }
    for(int i=0;i<4;i++){
        tca9548_set_channels(&i2c_switch, BIT(channels[i]));
        vl53l1x_init(vl53l1x_arr[i]);
        vl53l1x_setROISize(vl53l1x_arr[i], 4, 4);
        //vl53l1x_stopContinuous(vl53l1x_arr[i]);
        vl53l1x_startContinuous(vl53l1x_arr[i], 20000); // 50Hz
    }

    tca9548_set_channels(&i2c_switch, 7);
    TCS_init(TCS, 0, CONFIG_I2C_MASTER_SDA, CONFIG_I2C_MASTER_SCL);
    init();
    motor_init();
    xTaskCreatePinnedToCore(uart_slave_task, "uart_slave_task", configMINIMAL_STACK_SIZE * 3, NULL, 5, NULL, 0);
    xTaskCreatePinnedToCore(sensor_task, "sensor_task", configMINIMAL_STACK_SIZE * 3, NULL, 5, NULL, 1);
}

```

The function `xTaskCreatePinnedToCore` was used to create two simultaneously running tasks: `uart_slave_task` and `sensor_task.` This allowed the system to continuously gather data from the sensors while also responding to external requests. The sensor data is collected by-

```c
void sensor_task(void *pvParameters)
{
    float r = 0.0f, g = 0.0f, b = 0.0f;
    while(1)
    {
        tca9548_set_channels(&i2c_switch, BIT(3));
        vl53_distances[1] = vl53l1x_readSingle(vl53l1x_arr[1], 1); //right

        tca9548_set_channels(&i2c_switch, BIT(4));
        vTaskDelay(pdMS_TO_TICKS(10));
        vl53_distances[0] = vl53l1x_readSingle(vl53l1x_arr[0], 1); //Left

        tca9548_set_channels(&i2c_switch, BIT(5));
        vl53_distances[2] = vl53l1x_readSingle(vl53l1x_arr[2], 1); //front

        tca9548_set_channels(&i2c_switch, BIT(0));
        vl53_distances[3] = vl53l1x_readSingle(vl53l1x_arr[3], 1); //Back

        tca9548_set_channels(&i2c_switch, BIT(7));
        getlap(TCS, r, g, b);
        vTaskDelay(pdMS_TO_TICKS(10));
    }
}
```
The task is responsible for saving the information about the surroundings from ToF sensors and the color sensor for a sense of surrouding and counting laps. The output is saved in global variables and is waiting to be sent to the **master**.

The MCU board waits for commands from the main board. When a command is received, it reads the current sensor data from the global variables and stringifies it for transmission over UART. This approach was chosen for its simplicity and flexibility. Debug commands were left in place for each individual sensor, with an additional ALL command to request data from all sensors at once.

Full control over the driver motors is achieved through the `MF %d` and `MB %d` commands, where **MF means Motor Forward** and **MB means Motor Backward**. Each command expects a value between 0–100, representing the motor speed as a percentage. And sends a response to the well documented **TB6612FNG** using one PWM pin and Two direction control GPIOs. 

### Other Active Modules

| Component | Details | Image |
|---|---|---|
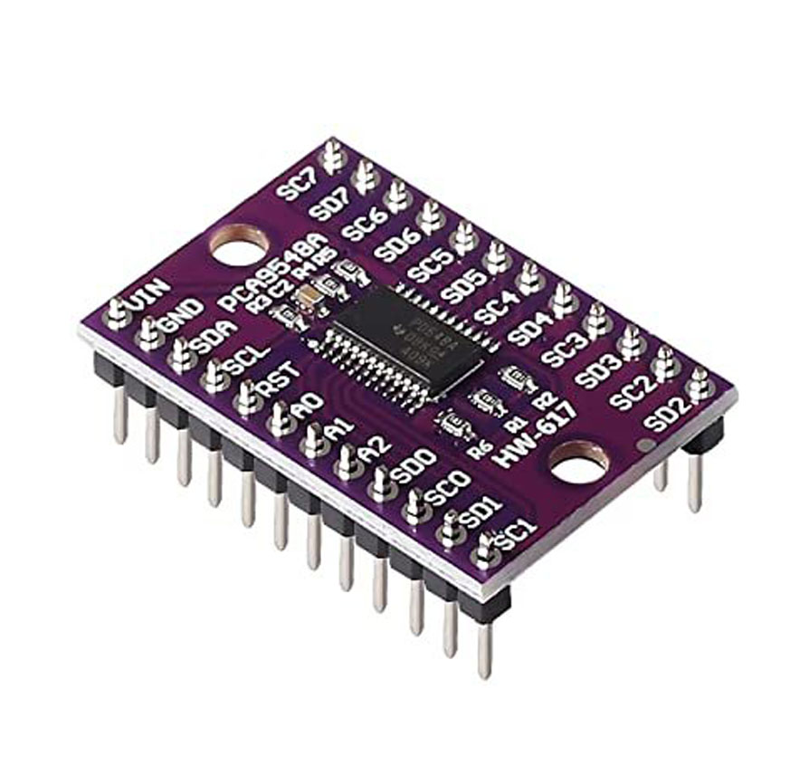
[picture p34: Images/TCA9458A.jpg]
| TCA9548A | I²C multiplexer, acts as the central hub for all onboard sensors |  |
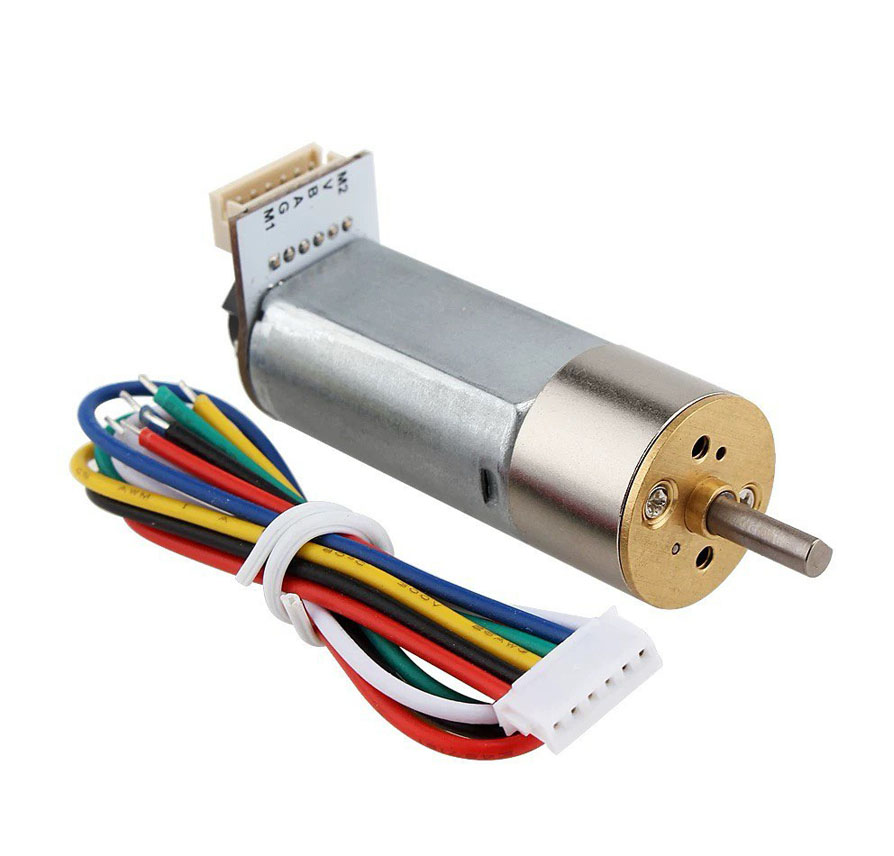
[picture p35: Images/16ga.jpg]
| 800RPM 16GA Motor |DC motor, used for vehicle propulsion and reliable drive |  |
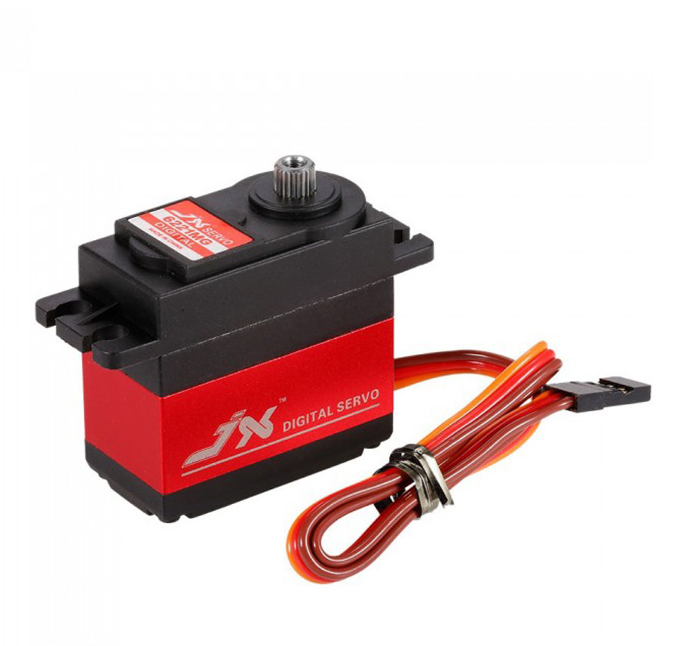
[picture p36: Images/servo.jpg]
| JX-6221-MGI Servo  | Precision servo motor, used to drive and control the steering system |  |

#### TCA9548A

We deliberately ensured that all our sensors communicated over the **I²C** protocol to avoid a tangled mess of wiring. The **TCA9548A multiplexer** was securely mounted under the K230 board, with all sensor cables neatly routed to their respective channels for organized and reliable communication.

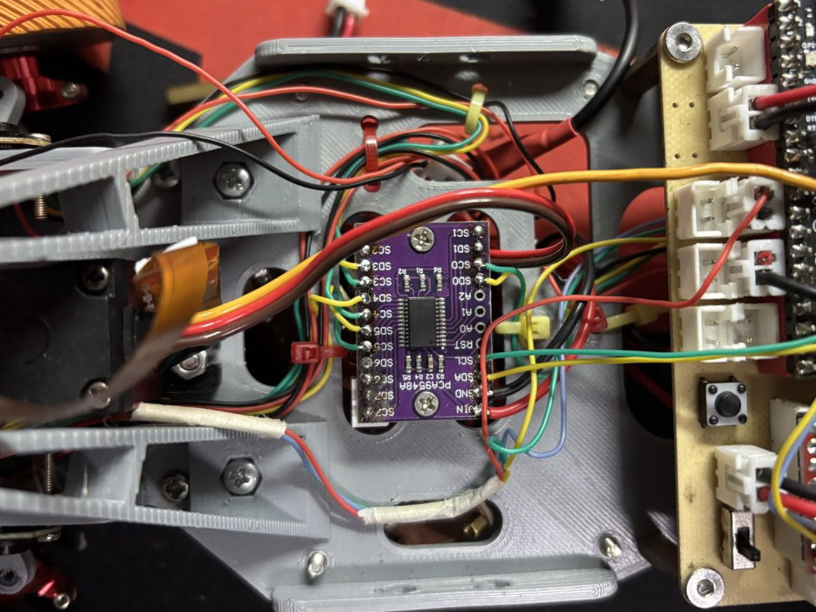
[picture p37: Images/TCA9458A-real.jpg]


#### 16GA 800RPM Motor

This motor proved to be very reliable, but its performance in our design was somewhat constrained. We overlooked the effect of the gear reduction and torque split at the differential, which meant the motor delivered only the minimum torque required for our application. To compensate, we increased the rear wheel diameter to recover some speed, and in future iterations we may consider slightly overvolting the motor or selecting a higher-torque alternative. Despite this limitation, the current setup has been sufficient for stable operation and provided valuable insight into drivetrain sizing.

### JX-6221-MGI Servo
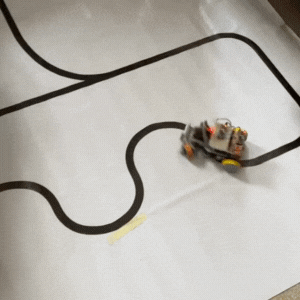
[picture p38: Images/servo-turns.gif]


Even though it may seem like overkill to use such a heavy-duty servo in a build like this, its accuracy and reliability far outperformed the smaller 9g alternatives. **At 6 V, it is rated for 0.16 s/60°**, and by running it on a clean **7.4 V supply** we were able to achieve even faster response times without compromising stability. 

# VI. Software Subsystem
[Overview](#overview--open-challenge-) · [Approach](#approach) · [Data Collection](#data-collection) · [Model Training](#model-training) · [Conclusion](#conclusion)
---
## Overview ( Open Challenge )
The car is controlled by a deep learning model trained using collected data from our trial runs to autonomously navigate through the track in the **WRO Open Challenge**

The car estimates its surrounding environment, and calculates its speed and required `steering angle` based on the proximity data from Time of Flight sensors and Neural Network on its chassis to navigate through the track and evade walls and obstacles.

---

## Approach
- Collect sensor data (`left`, `right`, `front`) from the ToF sensors while driving the car.  
- Record the **executed steering values** alongside sensor readings.  
- Augment the dataset with mirrored driving data.  
- Train a **deep learning regression model** to predict steering commands.  
- Deploy the trained model to a **K230 CanMV board** by converting to `.tflite` and `.kmodel` formats.  

---

## Data Collection

Example dataset:

```csv
left,right,front,steering
516.0,458.0,1719.0,3.0
516.0,463.0,1729.0,-2.0
508.0,463.0,1729.0,-7.0
```

**Left, Right, Front**: ToF sensor readings (distance values).

**Steering**: Control signal sent to the steering motor (in degrees).

The servo can rotate **270 degrees from its base position**, or **-135 to 135 degrees**. Our custom steering needs o**nly -22 to 22** to achieve reliable steering performance covering approximately 150 degrees. M**aximum steering angle recommended is -23 and 23** to avoid damage to the steering mechanism. It is strongly recommended to set **thresholds to the steering function from -22 to 22 or lower** to ensure safe steering.

```c
// Steering Function (mapped duty cycle)
void Servo(PWM servo, float angle) {
    // Map angle (-90~90) to duty (2.5~12.5)
    float duty = (angle + 90) / 180 * 10 + 2.5;
    servo.duty(duty);
}
```

**Data Augmentation (Mirrored Driving)**

When you only drive clockwise (or anticlockwise), you can generate mirrored data to simulate the opposite direction:

```python
df_mirrored = df.copy()  
df_mirrored[["left", "right"]] = df_mirrored[["right", "left"]].values
df_mirrored["steering"] = -df_mirrored["steering"]  

df = pd.concat([df, df_mirrored], ignore_index=True)
print("Augmented dataset shape:", df.shape)
```
This doubles our dataset and ensures the model learns symmetry. Data is collected in ``.txt`` format because the CanMV’s python implementation cannot generate and save data into a CSV file without taking major hurdles hence it is more feasible to convert it using utilities available online or methods like an example script added below:

```python
import pandas as pd

    # Assuming a space-delimited text file
    df = pd.read_csv('openclock2.txt', sep=r'\s+') 
    df.to_csv(‘penclock2.csv', index=False)
```

**Note:** This is barebones example is provided. Please adapt it according to requirement. Please look into the source code to see our implementation.

## Model Training

We used Google Colab for training:
Here is the attached ipynb file
[WRO_Open_Challenge_ML_Model.ipynb](src/Kendryte/WRO_Open_Challenge_ML_Model.ipynb)

**Required Libraries**
```python
import pandas as pd
import numpy as np
from sklearn.model_selection import train_test_split
from sklearn.preprocessing import StandardScaler
import tensorflow as tf
from tensorflow import keras
from tensorflow.keras import layers
```

**Preprocessing**

We restrict steering values to range [-22, 22] as per safety requirements of the steering mechanism and normalize to [-1, 1] for training:

```python
X = df[["left", "right", "front"]].values
y = df["steering"].values

# Scale steering
y = y / 22.0
```

Split dataset:

```python
X_train, X_test, y_train, y_test = train_test_split(
    X, y, test_size=0.2, random_state=42, shuffle=True
)

scaler = StandardScaler()
X_train = scaler.fit_transform(X_train)
X_test = scaler.transform(X_test)
```

**Deep Learning Model**
```python
model = keras.Sequential([
    layers.Input(shape=(X_train.shape[1],)),
    layers.Dense(32, activation="relu"),
    layers.Dense(32, activation="relu"),
    layers.Dense(16, activation="relu"),
    layers.Dense(1, activation="linear",
                 kernel_initializer="glorot_uniform",
                 bias_initializer="zeros")
])
```

**Explanation of Components**

- **ReLU (Rectified Linear Unit)** → f(x) = max(0, x)
  - Prevents negative activations, introduces non-linearity, avoids vanishing gradients.
- **Linear Activation (Output Layer)** → No transformation, keeps continuous range (for regression).
- **Glorot Uniform (Xavier Initialization)** → Distributes weights with controlled variance to stabilize training.
- **Bias Initializer = Zeros** → Ensures biases start neutral (no favoritism in predictions).

**Model Compilation**
```python
model.compile(
    optimizer=tf.keras.optimizers.Adam(learning_rate=0.001),
    loss=tf.keras.losses.Huber(),
    metrics=["mae"]
)
```

**Why These Choices?**

- **Adam Optimizer** → Adaptive learning rates for each parameter, faster convergence.
- **Huber Loss** → Less sensitive to outliers than MSE; combines MSE & MAE behavior.
- **MAE (Mean Absolute Error)** → Easy-to-interpret metric for regression (average absolute difference).

**Training**
```python
history = model.fit(
    X_train, y_train,
    validation_data=(X_test, y_test),
    epochs=500,
    batch_size=32,
    verbose=1
)
```

Epochs = 500 (you can adjust).

Batch size = 32 → Balanced mini-batch size.

Sample log:
```
Epoch 28/500
575/575 ━━━━━━━━━━━━━━━━ 2s 2ms/step 
loss: 0.0250 - mae: 0.1687 - val_loss: 0.0245 - val_mae: 0.1637

```

**Model Conversion**

Convert to TFLite for deployment:

```python
converter = tf.lite.TFLiteConverter.from_keras_model(model)
converter._experimental_lower_tensor_list_ops = True
converter.experimental_enable_resource_variables = False

tflite_model = converter.convert()
```

Then convert .tflite → .kmodel for CanMV K230 deployment.

**Converting from TFLite to Kmodel**

The CanMV K230 Board uses a specific kmodel format to load and run it’s kmodels and we need to use kendryte’s [nncase compiler](https://www.kendryte.com/k230/en/v1.5/01_software/board/ai/K230_nncase_Development_Guide.html). The compile environment is a Docker installation of Ubuntu 20.04 with necessary dependencies, so you need to install docker into your system. Procedure to set up the environment for compilation:-

```cmd
/* Get the K230 SDK. */
$ git clone https://github.com/kendryte/k230_sdk.git

/* build the dockerfile for docker */

$ cd k230_sdk

/* Pull all necessary components for nncase
$ make prepare_source
```
Now that it is ready, we need to copy the model.tflite to `k230_sdk/src/big/nncase/examples/models/model.tflite`

Now we can continue on the build process:-
```
$ sudo docker build -f tools/docker/Dockerfile -t k230_docker tools/docker

$ sudo docker run - root -it -v $(pwd):$(pwd) -v $(pwd)/toolchain/:opt/toolchain 
-w $(pwd) k230_docker/bin/bash

root@i650j345# pip install nncase nncase-kpu /* Need to do this everytime */
root@i650j345# cd src/big/nncase/examples
root@i650j345# python3 ./scripts/1.py —target k230 —model ./models/model.tflite
```
> **Note:** We provided a [1.py](src/Kendryte/1.py) script which must be used, default official scripts will not work. Please put it under `k230_sdk/big/nncase/examples/scripts` to complete the build or modify accordingly.

The `steering.kmodel` will be created in `tmp/steering`. Copy it and paste it to K230 board’s sd card’s root directory. You are ready to play around with it.

## Conclusion

- We collected sensor-steering pairs.
- Augmented dataset using mirroring.
- Trained a 3-layer neural network with ReLU activations.
- Used Adam + Huber Loss + MAE for stable regression.
- Deployed to K230 CanMV after converting to .kmodel.

The above pipeline enables our robot to navigate the path and precise steering control in accordance with trained data.

## Overview ( Obstacle Challenge )

We have initial breakthroughs on the obstacle round by combining the camera and the time of flight sensors. Every process is same except we are now collecting object data, and their poisiton in X and Y coordinates in the camera vision range, and also distance and proximity data. Our model trained with the data can now predict steering angle basing on the available data.

**Finding out object position and plotting boxes around it:-**
```python
        # Green
        green_blobs = img.find_blobs([green_threshold], pixels_threshold=20, area_threshold=20, merge=True)
        if green_blobs:
            biggest_green = max(green_blobs, key=lambda b: b.w() * b.h())
            x, y, w, h = biggest_green.rect()
            gx = x - 160
            gy = 240 - (y + h)
            if gy < 130:
                leftgreenx, leftgreeny = gx, gy
                img.draw_rectangle((x, y, w, h), color=(0, 255, 0))
                img.draw_cross(biggest_green.cx(), biggest_green.cy(), color=(255, 0, 0))

        # Red
        red_blobs = img.find_blobs([red_threshold], pixels_threshold=50, area_threshold=50, merge=True)
        if red_blobs:
            biggest_red = max(red_blobs, key=lambda b: b.w() * b.h())
            x, y, w, h = biggest_red.rect()
            rx = (x + w) - 160
            ry = 240 - (y + h)
            if ry < 130:
                rightredx, rightredy = rx, ry
                img.draw_rectangle((x, y, w, h), color=(255, 0, 0))
                img.draw_cross(biggest_red.cx(), biggest_red.cy(), color=(0, 255, 0))

```

**And then we collect the data to train it. The model predicts output by:-**
```python

def predict_steering(tfl, tfr, tff, leftgreenx, leftgreeny, rightredx, rightredy):
    try:
        steering = _try_run_with_array([tfl, tfr, tff, leftgreenx, leftgreeny, rightredx, rightredy])
        print(f"Raw steering: {steering}")
        steering = steering/100
        if steering < -22:
            steering = -22
        if steering > 22:
            steering = 22
        print(f"Final steering: {steering}")
        return steering
    except Exception as e:
        print("Model inference failed:", e)
        return 0.0

/* And in the main loop */

        # Green
        green_blobs = img.find_blobs([green_threshold], pixels_threshold=20, area_threshold=20, merge=True)
        if green_blobs:
            biggest_green = max(green_blobs, key=lambda b: b.w() * b.h())
            x, y, w, h = biggest_green.rect()
            gx = x - 160
            gy = 240 - (y + h)
            if gy < 130:
                leftgreenx, leftgreeny = gx, gy
                #img.draw_rectangle((x, y, w, h), color=(0, 255, 0))
                #img.draw_cross(biggest_green.cx(), biggest_green.cy(), color=(255, 0, 0))

        # Red
        red_blobs = img.find_blobs([red_threshold], pixels_threshold=50, area_threshold=50, merge=True)
        if red_blobs:
            biggest_red = max(red_blobs, key=lambda b: b.w() * b.h())
            x, y, w, h = biggest_red.rect()
            rx = (x + w) - 160
            ry = 240 - (y + h)
            if ry < 130:
                rightredx, rightredy = rx, ry
                #img.draw_rectangle((x, y, w, h), color=(255, 0, 0))
                #img.draw_cross(biggest_red.cx(), biggest_red.cy(), color=(0, 255, 0))

        # ------------------------------
        # ToF sensor data
        # ------------------------------
        front = get_sensor_data("TFF", "TFF", 20)
        left  = get_sensor_data("TFL", "TFL", 20)
        right = get_sensor_data("TFR", "TFR", 20)

        if left is None: left = last_valid["left"]
        else: last_valid["left"] = left
        if right is None: right = last_valid["right"]
        else: last_valid["right"] = right
        if front is None: front = last_valid["front"]
        else: last_valid["front"] = front

        now = time.ticks_ms()
        if time.ticks_diff(now, last_infer) >= 70:  # ~10 Hz
            try:
                print(f"\nRaw Sensors: L={left}, R={right}, F={front}, LG=({leftgreenx},{leftgreeny}), RR=({rightredx},{rightredy})")
                steering = predict_steering(left, right, front, leftgreenx, leftgreeny, rightredx, rightredy)
                print(f"→ Applied steering: {steering:.2f}°\n")
            except Exception as e:
                print("Inference error:", e)
                steering = 0.0
            last_infer = now

        Servo(S1, steering)
        Display.show_image(img)
        gc.collect()
        time.sleep_ms(20)
```
**Note:- This is subject to change, as we are still figuring out how to train the model with proper and adverse condition data to be able to precicely predict the turns in difficult situations. So as of 20/09/2025, we have not been able to sufficiently work on the obstacle round and parking algorithm due to our ongoing university's semsester final examinations, after which we will be able to dedicate time to implementing and testing the respective algorithms. Therefore, no further documentaion is available for presentation at this stage. Parking algorithm and its documentation is still in infancy, will be uploaded soon.**

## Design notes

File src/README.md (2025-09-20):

# Control software
====

A few attempts at finding the best method to detect colours and make an algorithm to avoid the objects. 
---

## Layout
```
ESP32S3/ - Folder containing files and build instructions for ESP32S3 firmwware.
Kendryte/ - Folder containing files, build and training instructions for K230 software and ML stack.
```
---

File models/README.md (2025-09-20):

## CAD Models

All CAD models required to recreate this vehicle are provided in this repository.  
The differential and steering knuckles were purchased off-the-shelf, but non-functional CAD models are also included for reference and measurement purposes.

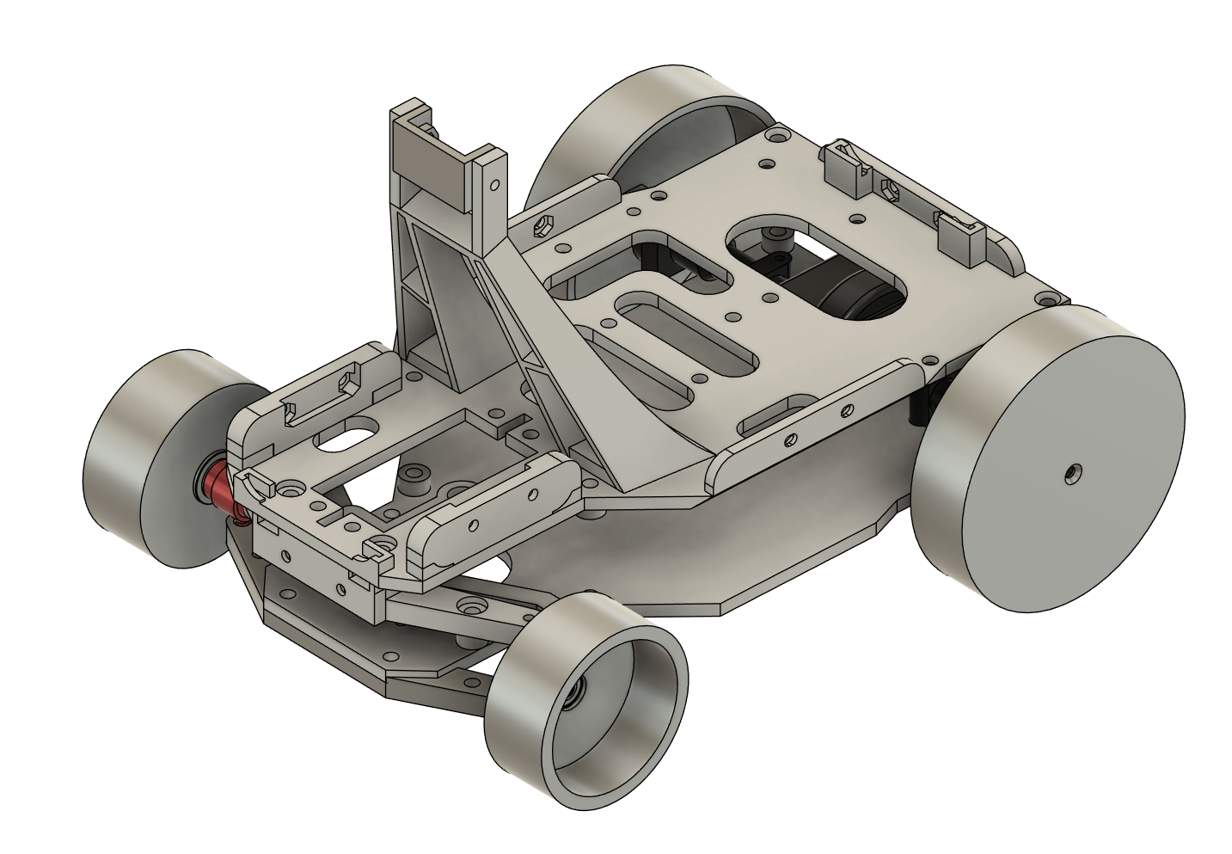
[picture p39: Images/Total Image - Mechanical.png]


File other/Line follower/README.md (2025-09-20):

# WRO Future Engineers 2025 – Team Barakah Brigade

We trained the data for the car utilizing a line follower approach, by making the car move through different routes inside the track, collecting the data and training models with it.

An additional ESP32S3 was to be connected to the steering servo, and data was collected by running Line follower code and an LFR sensor to the front and adding followable lines in the main track.

**Build Instructions:-**
1. Install ESP-IDF.
2. Export the variables and add them to path. Follow the [official documentation](https://docs.espressif.com/projects/esp-idf/en/stable/esp32s3/get-started/index.html#installation) 
We went without the VSCode approach in the terminal by

```
$ cd src/other/Line_follower/src/ESP32S3

/* Connect your ESP32-S3 device */

$ idf.py flash

```

And the ESP32-S3 will be ready to be used as a Line Follower Robot to gather Data.



**Important:- Make a note of the PIN names in the code. It must match the circuit. All our pins follow the GPXX layout in the official datasheet. Please refer to your own board pinout for reference. Below is an attached table with our pin assingments.**

| Pin | Function|
|---|---|
| GP13-14 | UART RX-TX |
| GP17 | Servo PWM |

*Team Barakah Brigade, 2025*

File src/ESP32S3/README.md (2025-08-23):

# ESP32S3 Sensor hub.

This is the firmware source code for the ESP32s3 board in our system responsible for offloading various tasks from the mainboard, for example taking care of handling data from the sensors. We made it a bit differently, so that this device is can be communicated with defined commands, much akin to a prompt.As of now, the commands are integers 1 to 16 accesses the respective index of the sensor data storage buffer `rx_buffer[]`, and the required data is sent.  This approach was chosen to keep the board versatile, adaptive, and change/testing friendly because we needed to update the sensors or the design of the car. Note that this project is still in development and we need to organize the code for better reliability.

---

## How does it work?

We made the ESP32s3 act as a master for the sensors, which collect the data and ESP32s3 board calculates the distance in this project. The project uses [tca9548](https://github.com/esp-idf-lib/tca9548) I2C multiplexer to add additional ports for sensors with same/similar behavior and same addresses. Commands 1 to 4 mean `VL53L0X` sensor's distance measurement from 1,2,3,4 meaning right front left back respectively. commands 11 to 15 are mirrored in the same way for `VL53L1X`. 

Now, one might ask why did we do this? It is because we originally started with VL53L0X and we were pretty much okay with it. But VL53L1X's feature of sampling distances @50Hz was quite a compelling feature to us to the project if we wanted to increase the car's speed without sacrificing the accuracy of the distance measurement thus achieving a more reliable and safe system even at faster speeds.

In addition to ToF sensors for distance measurement, we did the same with Ultrasonic sensors, however they are not connected through I2C, rather they are connected through PWM to the ESP32s3 board. We decided to adventure with different sensors, and ultrasonic sensors have long been used for the purpose. We used the [esp-idf-lib ultrasonic sensor](https://github.com/esp-idf-lib/ultrasonic) library for this because the library had the temperature compensated distance measurement function `ultrasonic_measure_cm_temp_compensated`.

The ToF libraries were take from 
    1. [ESP32-VL53L0X](https://github.com/revk/ESP32-VL53L0X)
    2. [ESP32-VL53L1X](https://github.com/revk/ESP32-VL53L1X)
    
Distance data acquired from ToFs are in millimeters and for ultrasonic sensors, as the function suggests, returns the data in centimeters. This data is directly transferred to the main board via the I2C bus based on the received command.

Moreover, we have added the [TCS34725](https://github.com/tcs34725) RGB sensor for counting the laps in the path for the challenge. We are conflicted on deciding if this simple task of counting laps be left to be done by this sensor hub or by the main board as the RGB data needs to be processed and match with the track's color lines present in different locations to decide when a lap is completed. Preferring to make the lap calculation in the mainboard for now, subject to change later.

---

## A bit of description about the task handling

Since the system is supposed to be mostly in motion, it is important to have the latest data in the shortest intervals. However doing them in a regular, simple and streamlined flow might make the whole process slower than it needs to be. Hence, we went with the FreeRTOS build of ESP32s3 firmware. It allows us to run multiple tasks at once, and we are running two such tasks. One is `sensor_task` which continuously samples data from the sensor and handles the calculation. And another task, `slave_task` waits for a command in it's I2C slave port. Once a command is received, data of that instant is sent to the master.

We are currently working on a STOP command, which will make the mainboard terminate every process once the required number of laps is complete.

---

## How to work with the code?

We tried to make the main base of the firmware source to be modular and potentially integrate with many other projects, afterall main goal of this board was to be a flexible, adaptive and configurable sensor expansion board. So it is possible to integrate the source with any other projects as long as it is based on ESP-IDF

For requirements, please check out the dependencies for ESP-IDF installation. Here is a step by step guide for beginners to work with the firmware:-
    1. Install ESP-IDF and its dependencies from the official espressif site. Alternatively, esp-idf extension for VSCode is also available. Make sure the dependencies are available in your system before you install the VSCode extension.

    2. After installation, clone UncleRus's esp-idf-lib repo somewhere for the `tca9548`, `ultrasonic sensors`, `tcs34725`. Follow the repo for installation instructions and how to integrate the extra components into the esp-idf project.

    3. Make sure to close the default bash prompt of VSCode if you are using the VSCode extension method. Open ESP-IDF terminal from the bottom, it should look like a console icon.

    4. From there run `idf.py menuconfig` Do not change anything, save it by clicking S and Esc and press Q to quit.

    5. The build environment for the project should be ready. run idf.py build for building the firmware, followed by idf.py -p PORT flash to flash it to your ESP32S3. Replace port with the actual port where the ESP32S3 is connected.
    
    6. Ready to test and tinker!

---
*Team Barakah Brigade, 2025*

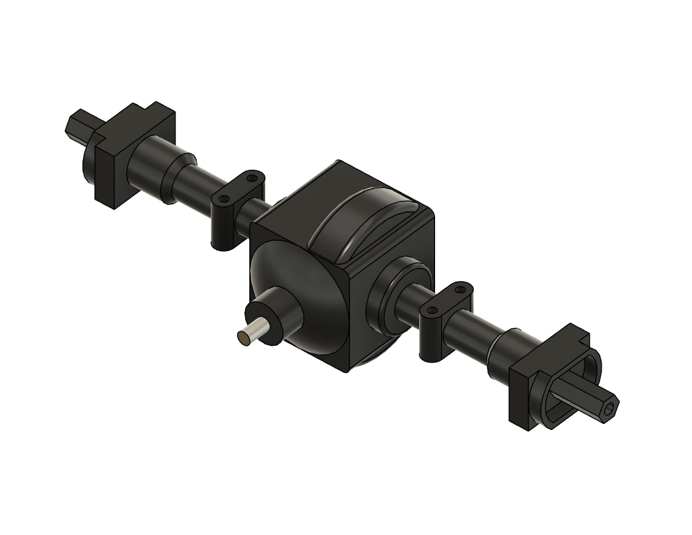
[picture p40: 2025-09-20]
v-photos/differential - Mechanical.png

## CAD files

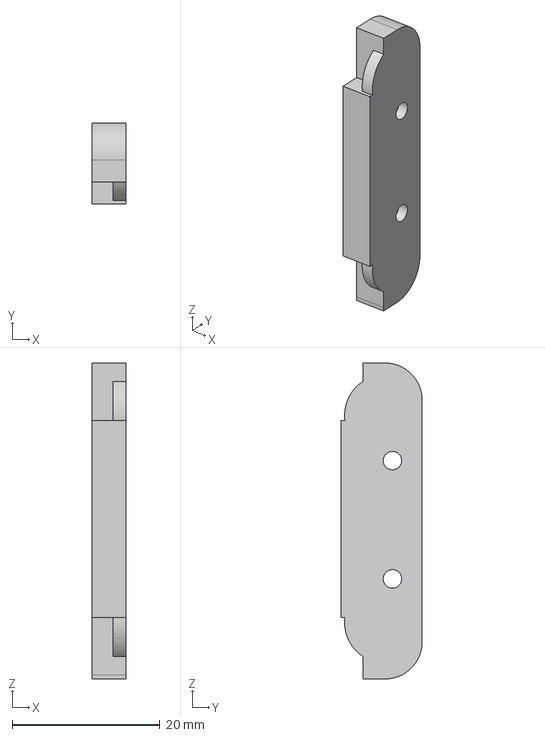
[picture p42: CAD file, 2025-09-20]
models/ToF-Mount-Right.step
4.65 x 11.0 x 42.7 mm

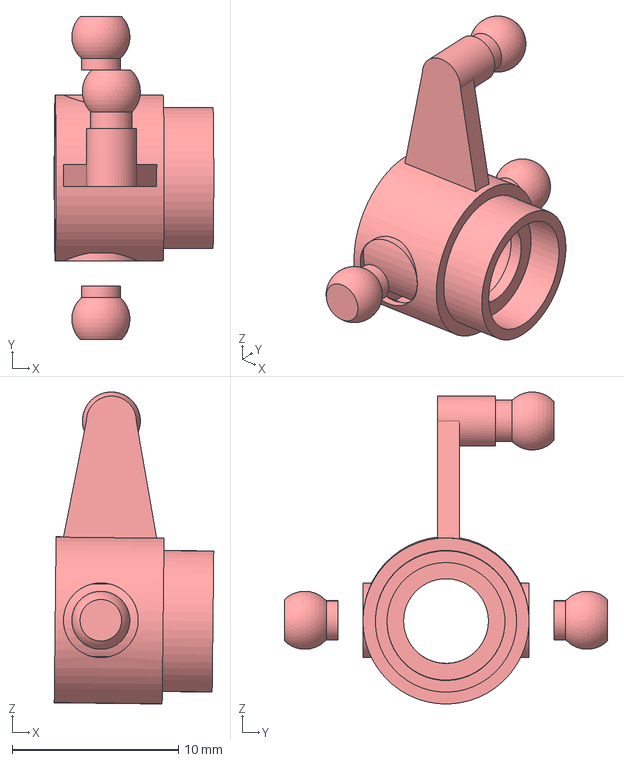
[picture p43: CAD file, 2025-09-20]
models/Knuckle-Right(Only For Demonstration).step
9.60 x 19.4 x 18.8 mm

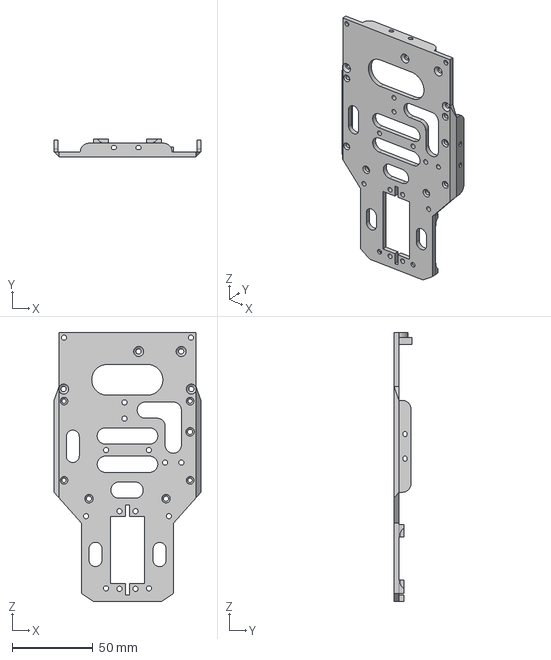
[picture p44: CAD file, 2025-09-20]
models/Top.step
90.9 x 11.0 x 166.4 mm

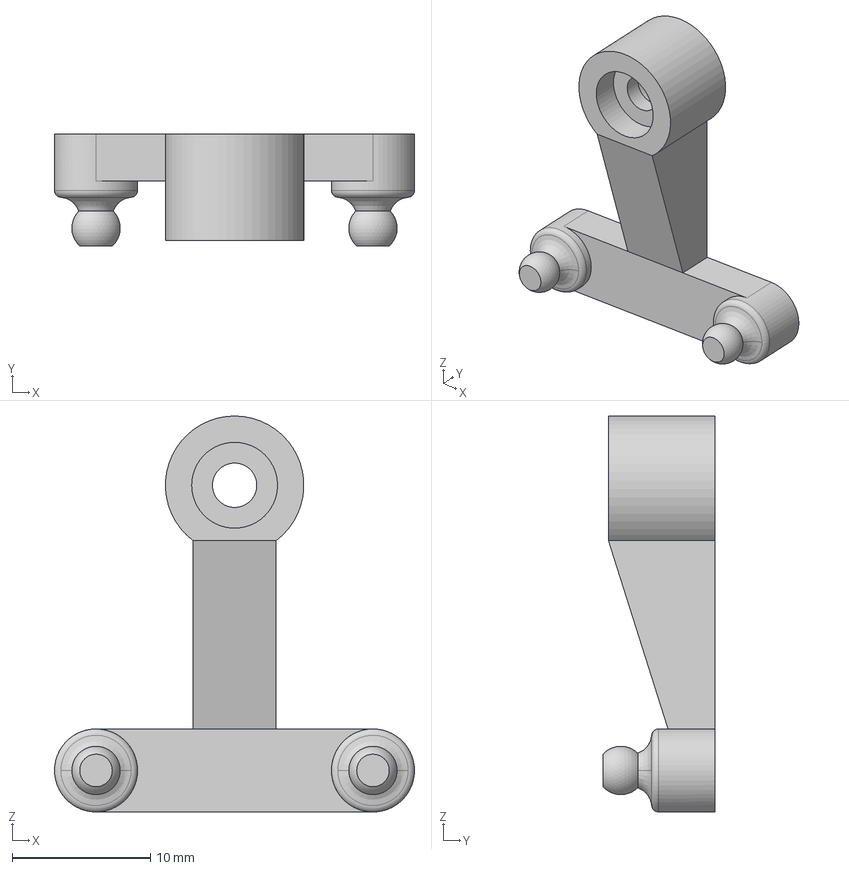
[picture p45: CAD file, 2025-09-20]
models/Servo-horn.step
26.0 x 8.10 x 28.6 mm

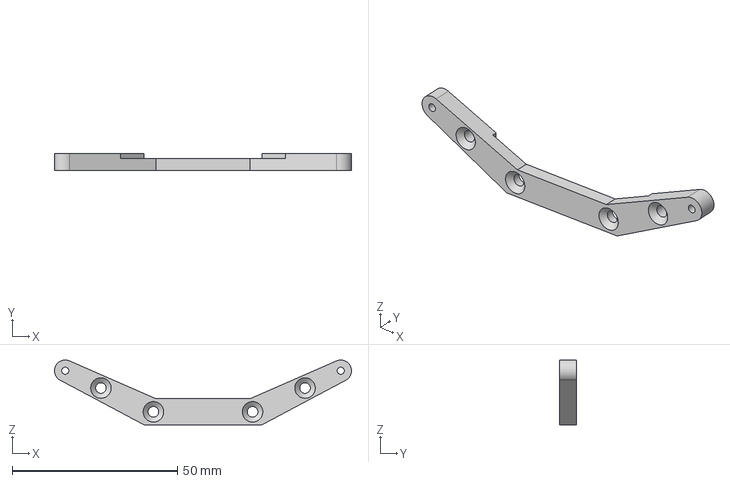
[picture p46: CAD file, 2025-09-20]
models/Steering-Base.step
89.8 x 5.00 x 19.7 mm

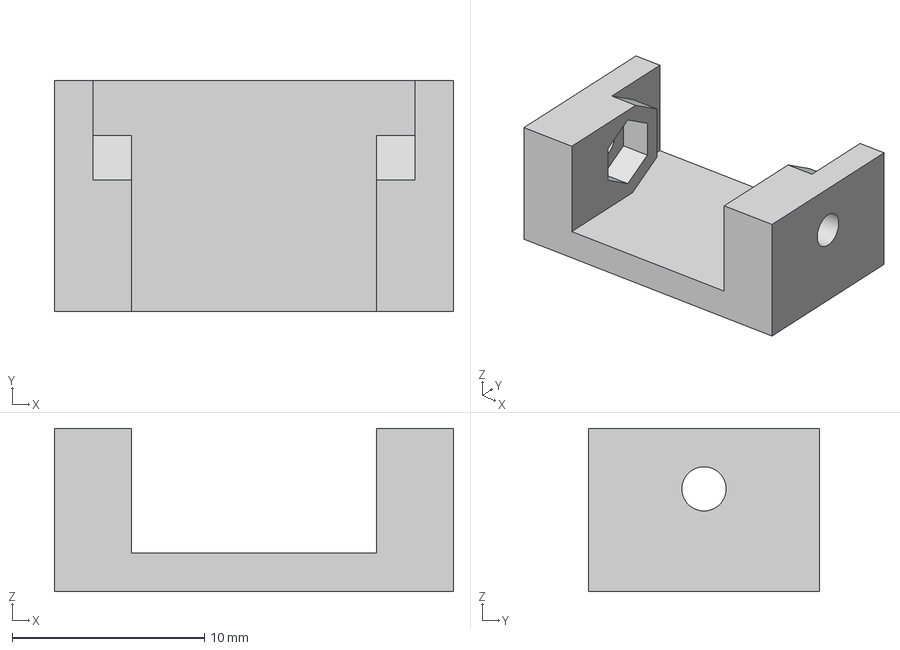
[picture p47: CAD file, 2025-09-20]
models/Camera-Mount-Pivot.step
20.8 x 12.0 x 8.50 mm

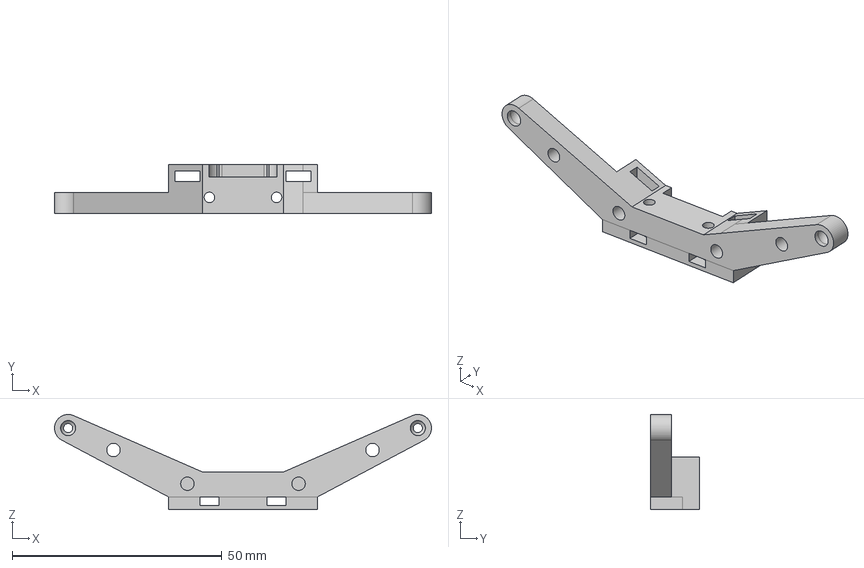
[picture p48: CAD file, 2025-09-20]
models/Steering-Top.step
89.8 x 11.7 x 22.7 mm

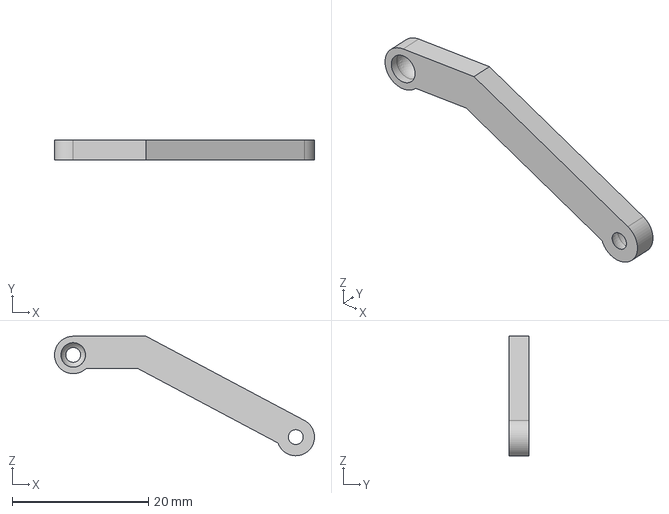
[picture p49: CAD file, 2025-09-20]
models/Tie-Rod-Right.step
38.2 x 3.00 x 17.6 mm

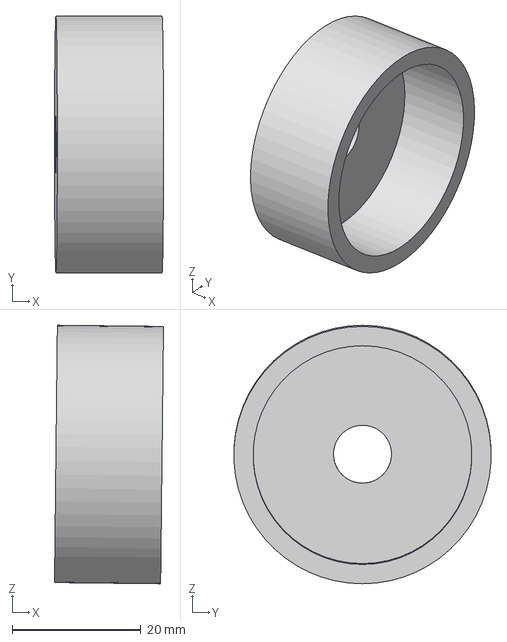
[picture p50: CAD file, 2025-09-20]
models/Front-Wheel.step
16.9 x 39.9 x 40.2 mm

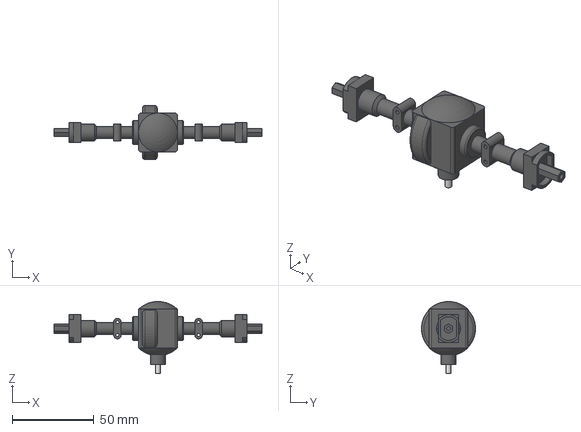
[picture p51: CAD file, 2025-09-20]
models/Differential(Only For Demonstration).step
126.8 x 32.9 x 44.0 mm

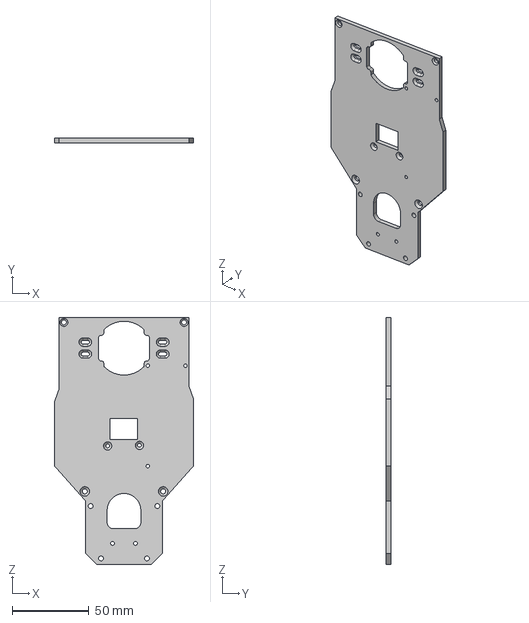
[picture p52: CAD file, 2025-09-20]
models/Base.step
90.9 x 3.00 x 161.4 mm

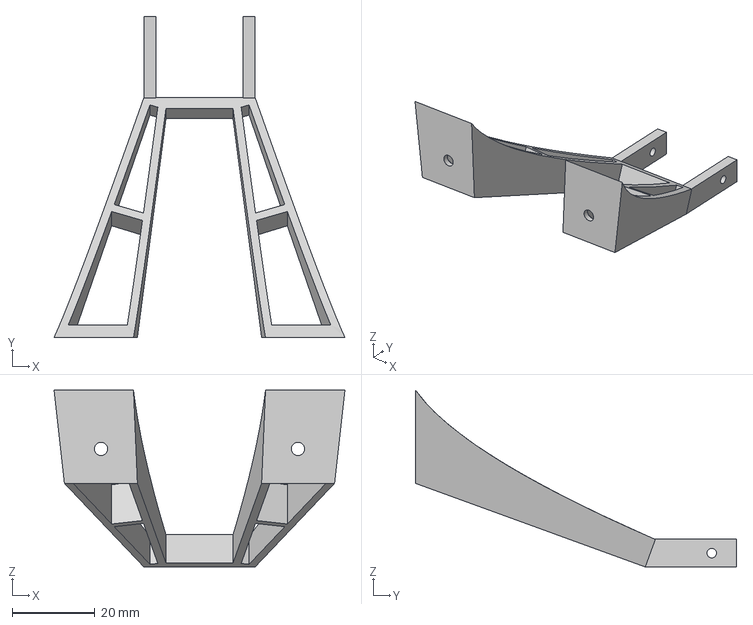
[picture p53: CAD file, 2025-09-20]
models/Camera-Mount-Body.step
70.5 x 77.7 x 42.9 mm

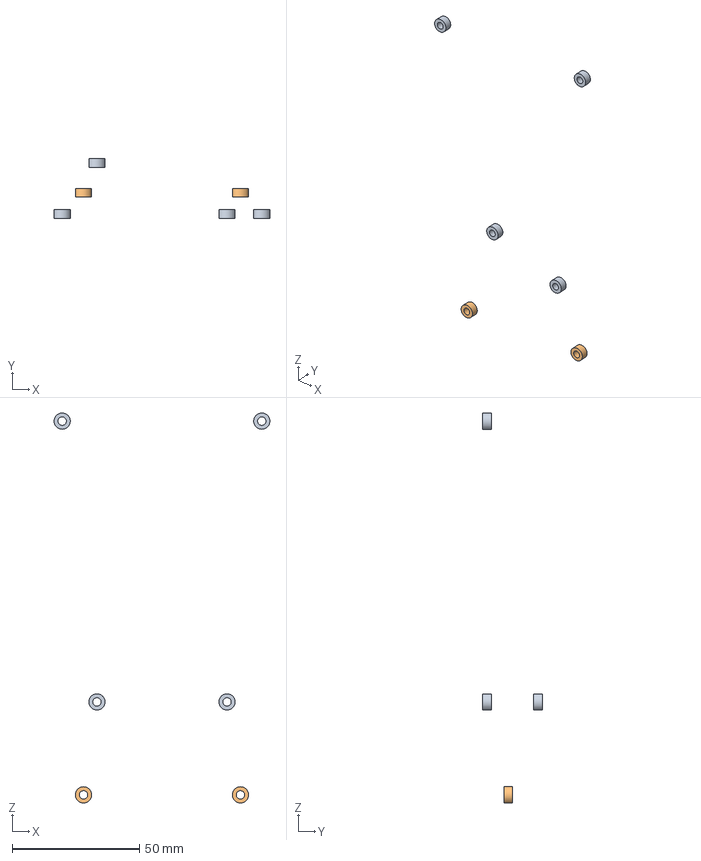
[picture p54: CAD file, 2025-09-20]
models/Spacer-20mm-Hex.step
84.9 x 23.5 x 153.4 mm

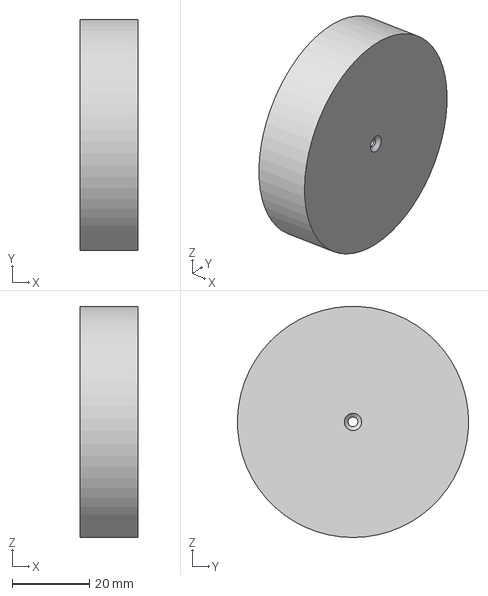
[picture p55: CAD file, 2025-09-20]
models/Rear-Wheel-60mm.step
15.0 x 60.0 x 60.0 mm

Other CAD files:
models/ToF-Mount-Left.step
models/Knucke-Left(Only For Demonstration).step
models/Tie-Rod-Left.step

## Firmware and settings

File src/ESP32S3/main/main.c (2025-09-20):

/**********************************************************************************
 * 
 * 
 *  Copyright 2025 Alif Ilhan https://github.com/alifilhan0
 *  This is the firmware for esp32s3 sensor daughter board.
 *  I have created two tasks in the firmware, and they will keep updating
 *  the rx buffer with sensor data. And a slave task, which just waits for the master
 *  to send a command, it will respond according to command.
 * 
 * 
 *  TODO:- Add slave writeback to the master functionality
 * 
 * 
 **********************************************************************************/

#include <stdio.h>
#include <string.h>
#include <math.h>
#include <freertos/FreeRTOS.h>
#include <freertos/task.h>
#include <esp_system.h>
#include <driver/i2c.h>
#include <tca9548.h>
#include "freertos/projdefs.h"
#include "vl53l1x.h"
#include "driver/uart.h"
#include "string.h"
#include "driver/gpio.h"
#include "driver/mcpwm.h"
//#include "mpu6050.h"
//#include "quaternions.h"
//#include "roll_pitch.h"
#include "driver/gpio.h"
#include "tcs34725.h"

#define BUTTON_GPIO GPIO_NUM_40

#define MAX_DISTANCE_CM 500

// Global buffers for sensor data
static uint16_t vl53_distances[6] = {0};

ESP32_TCS34725 *TCS = NULL;
// TCA9548 and VL53L1X
static vl53l1x_t *vl53l1x_arr[6];
static i2c_dev_t i2c_switch = {0};

static const int RX_BUF_SIZE = 1024;

#define TXD_PIN (13)
#define RXD_PIN (14)

#define MOTOR_PWM_UNIT MCPWM_UNIT_0
#define MOTOR_TIMER MCPWM_TIMER_0
#define MOTOR_GEN_A MCPWM_OPR_A
#define MOTOR_GEN_B MCPWM_OPR_B
#define PWM_FREQ_HZ 1000

#define DIR_A1 4
#define DIR_A2 2
#define PWM_A 8
#define STBY 33
int level = 1;
int lap = 0;;
int color;


void motor_init() {
    // Direction pins
    gpio_set_direction(DIR_A1, GPIO_MODE_OUTPUT);
    gpio_set_direction(DIR_A2, GPIO_MODE_OUTPUT);
    // Standby pin
    gpio_set_direction(STBY, GPIO_MODE_OUTPUT);
    mcpwm_gpio_init(MCPWM_UNIT_0, MCPWM0A, PWM_A);

    mcpwm_config_t pwm_config = {
        .frequency = 1000,
        .cmpr_a = 0,
        .cmpr_b = 0,
        .counter_mode = MCPWM_UP_COUNTER,
        .duty_mode = MCPWM_DUTY_MODE_0
    };
    mcpwm_init(MCPWM_UNIT_0, MCPWM_TIMER_0, &pwm_config);
}

// speed_percent: 0-100, direction: 1=forward, 0=reverse
void motor_set(int speed_percent, int direction) {
    if(direction == 2) {
        gpio_set_level(DIR_A1, 1);
        gpio_set_level(DIR_A2, 0);
    } else if(direction == 1) {
        gpio_set_level(DIR_A1, 0);
        gpio_set_level(DIR_A2, 1);
    } else if(direction == 0) {
        gpio_set_level(DIR_A1, 0);
        gpio_set_level(DIR_A2, 0);
    }
    mcpwm_set_duty(MCPWM_UNIT_0, MCPWM_TIMER_0, MCPWM_OPR_A, speed_percent);
}

int getlap(ESP32_TCS34725 *TCS, float r, float g, float b)
{
    TCS_getRGB(TCS, &r, &g, &b);
    int rgb = (((int)r << 16) | ((int)g << 8) | ((int)b << 0));
    uint16_t temp = calculateColorTemperature(r, g, b); // Alif: - Maybe used later for an even better algorithm
    uint16_t lux = calculateLux(r, g, b); // Alif :- Maybe used later for an even better algorithm
    if(rgb >= 0xdc0000 || rgb <= 0x00dddd) // dc0000 = reference reddish low orange value. 00dddd = reference bright blue value used for lap counting
    {
        lap++;
    }
}

void sensor_task(void *pvParameters)
{
    float r = 0.0f, g = 0.0f, b = 0.0f;
    while(1)
    {
        tca9548_set_channels(&i2c_switch, BIT(3));
        vl53_distances[1] = vl53l1x_readSingle(vl53l1x_arr[1], 1); //right

        tca9548_set_channels(&i2c_switch, BIT(4));
        vTaskDelay(pdMS_TO_TICKS(10));
        vl53_distances[0] = vl53l1x_readSingle(vl53l1x_arr[0], 1); //Left

        tca9548_set_channels(&i2c_switch, BIT(5));
        vl53_distances[2] = vl53l1x_readSingle(vl53l1x_arr[2], 1); //front

        tca9548_set_channels(&i2c_switch, BIT(0));
        vl53_distances[3] = vl53l1x_readSingle(vl53l1x_arr[3], 1); //Back


        tca9548_set_channels(&i2c_switch, BIT(7));
        getlap(TCS, r, g, b);
        vTaskDelay(pdMS_TO_TICKS(10));
    }
}

void init(void)
{
    const uart_config_t uart_config = {
        .baud_rate = 115200,
        .data_bits = UART_DATA_8_BITS,
        .parity = UART_PARITY_DISABLE,
        .stop_bits = UART_STOP_BITS_1,
        .flow_ctrl = UART_HW_FLOWCTRL_DISABLE,
        .source_clk = UART_SCLK_DEFAULT,
    };
    // We won't use a buffer for sending data.
    uart_driver_install(UART_NUM_1, RX_BUF_SIZE * 2, 0, 0, NULL, 0);
    uart_param_config(UART_NUM_1, &uart_config);
    uart_set_pin(UART_NUM_1, TXD_PIN, RXD_PIN, UART_PIN_NO_CHANGE, UART_PIN_NO_CHANGE);
}

// Handle received UART commands
void handle_command(char* cmd) {
    char response[64];

    if (strncmp(cmd, "TFL", 3) == 0) {
        snprintf(response, sizeof(response), "TFL:%hu\n", vl53_distances[0]);
    } else if (strncmp(cmd, "TFR", 3) == 0) {
        snprintf(response, sizeof(response), "TFR:%hu\n", vl53_distances[1]);
    } else if (strncmp(cmd, "TFB", 3) == 0) {
        snprintf(response, sizeof(response), "TFB:%hu\n", vl53_distances[3]);
    } else if (strncmp(cmd, "TFF", 3) == 0) {
        snprintf(response, sizeof(response), "TFF:%hu\n", vl53_distances[2]);
    } else if (strncmp(cmd, "MF", 2) == 0) {
        int buf = atoi(cmd + 2);
        motor_set(buf, 2);
        snprintf(response, sizeof(response), "MF %d\n", buf);
    } else if (strncmp(cmd, "ALL", 3)) {
        snprintf(response, sizeof(response), "ALL:%04hu%04hu%04hu%04hu\n", vl53_distances[0], vl53_distances[1], vl53_distances[2], vl53_distances[3]); //get all data at once
        vTaskDelay(pdMS_TO_TICKS(30));
    } else if (strncmp(cmd, "MB", 2) == 0) {
        int buf = atoi(cmd + 2);
        motor_set(buf, 1);
        snprintf(response, sizeof(response), "MB %d\n", buf);
    } else if (strncmp(cmd, "STOP", 4) == 0) {
        motor_set(0, 0);
        snprintf(response, sizeof(response), "STOP\n");
    } else if (strncmp(cmd, "LAP", 5) == 0) {
        snprintf(response, sizeof(response), "%d\n", lap);
    } else {
        snprintf(response, sizeof(response), "ERROR:UNKNOWN_CMD\n");
    }

    uart_write_bytes(UART_NUM_1, response, strlen(response));
}

void uart_slave_task(void *arg)
{
    char* data = (char*) malloc(RX_BUF_SIZE + 1);
    while(1)
    {
        const int rxBytes = uart_read_bytes(UART_NUM_1, data, RX_BUF_SIZE, 10 / portTICK_PERIOD_MS);
        if (rxBytes > 0) {
            data[rxBytes] = 0;
            handle_command(data);
        }
    }
}

void button_init(void) {
    gpio_config_t io_conf = {
        .pin_bit_mask = 1ULL << 40,  // GPIO40
        .mode = GPIO_MODE_INPUT,
        .pull_up_en = GPIO_PULLUP_DISABLE,
        .pull_down_en = GPIO_PULLDOWN_DISABLE,
        .intr_type = GPIO_INTR_DISABLE
    };
    gpio_config(&io_conf);
}

void app_main()
{
    ESP_ERROR_CHECK(i2cdev_init());
    tca9548_init_desc(&i2c_switch, 0x70, 0, CONFIG_I2C_MASTER_SDA, CONFIG_I2C_MASTER_SCL);

    const uint8_t channels[4] = {0,4,3,5};
    for(int i=0;i<4;i++){
        tca9548_set_channels(&i2c_switch, BIT(channels[i]));
        vl53l1x_arr[i] = vl53l1x_config(0, CONFIG_I2C_MASTER_SCL, CONFIG_I2C_MASTER_SDA, -1, 0x29, 0);
    }
    for(int i=0;i<4;i++){
        tca9548_set_channels(&i2c_switch, BIT(channels[i]));
        vl53l1x_init(vl53l1x_arr[i]);
        vl53l1x_setROISize(vl53l1x_arr[i], 4, 4);
        //vl53l1x_stopContinuous(vl53l1x_arr[i]);
        vl53l1x_startContinuous(vl53l1x_arr[i], 20000); // 50Hz
    }

    tca9548_set_channels(&i2c_switch, 7);
    TCS_init(TCS, 0, CONFIG_I2C_MASTER_SDA, CONFIG_I2C_MASTER_SCL);
    init();
    motor_init();
    xTaskCreatePinnedToCore(uart_slave_task, "uart_slave_task", configMINIMAL_STACK_SIZE * 3, NULL, 5, NULL, 0);
    xTaskCreatePinnedToCore(sensor_task, "sensor_task", configMINIMAL_STACK_SIZE * 3, NULL, 5, NULL, 1);
}

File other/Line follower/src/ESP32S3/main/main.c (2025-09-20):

#include <stdio.h>
#include <string.h>
#include <math.h>
#include <freertos/FreeRTOS.h>
#include <freertos/task.h>
#include <esp_system.h>
#include "freertos/projdefs.h"
#include "driver/uart.h"
#include "string.h"
#include "driver/gpio.h"
#include "common.h"
#define TXD_PIN (13)
#define RXD_PIN (14)

static const int RX_BUF_SIZE = 1024;


void uart_init(void)
{
    const uart_config_t uart_config = {
        .baud_rate = 115200,
        .data_bits = UART_DATA_8_BITS,
        .parity = UART_PARITY_DISABLE,
        .stop_bits = UART_STOP_BITS_1,
        .flow_ctrl = UART_HW_FLOWCTRL_DISABLE,
        .source_clk = UART_SCLK_DEFAULT,
    };
    uart_driver_install(UART_NUM_1, RX_BUF_SIZE * 2, RX_BUF_SIZE * 2, 0, NULL, 0);
    uart_param_config(UART_NUM_1, &uart_config);
    uart_set_pin(UART_NUM_1, TXD_PIN, RXD_PIN, UART_PIN_NO_CHANGE, UART_PIN_NO_CHANGE);
}

void handle_command(char* cmd) {
    char response[64];

    if (strncmp(cmd, "ANG", 3) == 0) {
        snprintf(response, sizeof(response), "ANG:%d\n", angle);
    } else {
        snprintf(response, sizeof(response), "ERROR:UNKNOWN_CMD\n");
    }

    vTaskDelay(pdMS_TO_TICKS(20));
    uart_write_bytes(UART_NUM_1, response, strlen(response));
}

void uart_task(void *arg)
{
    char* data = (char*) malloc(RX_BUF_SIZE + 1);
    while(1)
    {
        const int rxBytes = uart_read_bytes(UART_NUM_1, data, RX_BUF_SIZE, 10 / portTICK_PERIOD_MS);
        if (rxBytes > 0) {
            data[rxBytes] = 0;
            handle_command(data);
        }
    }
}

void app_main(void)
{
    uart_init();
    adc_init();
    servo_init();
    gpio_set_direction(S0, GPIO_MODE_OUTPUT);
    gpio_set_direction(S1, GPIO_MODE_OUTPUT);
    gpio_set_direction(S2, GPIO_MODE_OUTPUT);
    ESP_ERROR_CHECK(mcpwm_comparator_set_compare_value(comparator, example_angle_to_compare(-20))); //-20
    vTaskDelay(pdMS_TO_TICKS(500));
    ESP_ERROR_CHECK(mcpwm_comparator_set_compare_value(comparator, example_angle_to_compare(0)));
    vTaskDelay(pdMS_TO_TICKS(500));
    ESP_ERROR_CHECK(mcpwm_comparator_set_compare_value(comparator, example_angle_to_compare(20))); //20
    vTaskDelay(pdMS_TO_TICKS(500));
    ESP_ERROR_CHECK(mcpwm_comparator_set_compare_value(comparator, example_angle_to_compare(0)));
    xTaskCreatePinnedToCore(uart_task, "uart_task", 4096, NULL, 6, NULL, 0);
    xTaskCreatePinnedToCore(PID, "PID", 8192, NULL, 5, NULL, 1);
}

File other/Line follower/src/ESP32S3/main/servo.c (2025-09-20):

/*
 * SPDX-FileCopyrightText: 2022-2023 Espressif Systems (Shanghai) CO LTD
 *
 * SPDX-License-Identifier: Apache-2.0
 */

#include "freertos/FreeRTOS.h"
#include "freertos/task.h"
#include "esp_log.h"
#include "driver/mcpwm_prelude.h"
#include "common.h"
static const char *TAG = "Servo";

// Please consult the datasheet of your servo before changing the following parameters
#define SERVO_MIN_PULSEWIDTH_US 500  // Minimum pulse width in microsecond
#define SERVO_MAX_PULSEWIDTH_US 2500  // Maximum pulse width in microsecond
#define SERVO_MIN_DEGREE        -90   // Minimum angle
#define SERVO_MAX_DEGREE        90    // Maximum angle

#define SERVO_PULSE_GPIO             17        // GPIO connects to the PWM signal line
#define SERVO_TIMEBASE_RESOLUTION_HZ 1000000  // 1MHz, 1us per tick
#define SERVO_TIMEBASE_PERIOD        20000    // 20000 ticks, 20ms

adc_oneshot_unit_handle_t adc2_handle;
adc_cali_handle_t adc2_cali_handle = NULL;
mcpwm_cmpr_handle_t comparator = NULL;
bool do_calibration2 = false;

uint32_t example_angle_to_compare(int angle)
{
    if(angle > 16) angle = 16; //20
    if(angle < -16) angle =-16; //-20
    return ((angle + CALIBRATION) - SERVO_MIN_DEGREE) * (SERVO_MAX_PULSEWIDTH_US - SERVO_MIN_PULSEWIDTH_US) / (SERVO_MAX_DEGREE - SERVO_MIN_DEGREE) + SERVO_MIN_PULSEWIDTH_US;
}

long map(long x, long in_min, long in_max, long out_min, long out_max) {
    return (x - in_min) * (out_max - out_min) / (in_max - in_min) + out_min;
}

void servo_init(void)
{
    mcpwm_timer_handle_t timer = NULL;
    mcpwm_timer_config_t timer_config = {
        .group_id = 0,
        .clk_src = MCPWM_TIMER_CLK_SRC_DEFAULT,
        .resolution_hz = SERVO_TIMEBASE_RESOLUTION_HZ,
        .period_ticks = SERVO_TIMEBASE_PERIOD,
        .count_mode = MCPWM_TIMER_COUNT_MODE_UP,
    };
    mcpwm_new_timer(&timer_config, &timer);

    mcpwm_oper_handle_t oper = NULL;
    mcpwm_operator_config_t operator_config = {
        .group_id = 0, // operator must be in the same group to the timer
    };
    mcpwm_new_operator(&operator_config, &oper);

    mcpwm_operator_connect_timer(oper, timer);

    mcpwm_comparator_config_t comparator_config = {
        .flags.update_cmp_on_tez = true,
    };
    mcpwm_new_comparator(oper, &comparator_config, &comparator);

    mcpwm_gen_handle_t generator = NULL;
    mcpwm_generator_config_t generator_config = {
        .gen_gpio_num = SERVO_PULSE_GPIO,
    };
    mcpwm_new_generator(oper, &generator_config, &generator);

    // set the initial compare value, so that the servo will spin to the center position
    mcpwm_comparator_set_compare_value(comparator, example_angle_to_compare(0));

    // go high on counter empty
    mcpwm_generator_set_action_on_timer_event(generator,
                                                              MCPWM_GEN_TIMER_EVENT_ACTION(MCPWM_TIMER_DIRECTION_UP, MCPWM_TIMER_EVENT_EMPTY, MCPWM_GEN_ACTION_HIGH));
    // go low on compare threshold
    mcpwm_generator_set_action_on_compare_event(generator,
                                                                MCPWM_GEN_COMPARE_EVENT_ACTION(MCPWM_TIMER_DIRECTION_UP, comparator, MCPWM_GEN_ACTION_LOW));

    mcpwm_timer_enable(timer);
    mcpwm_timer_start_stop(timer, MCPWM_TIMER_START_NO_STOP);

}

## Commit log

2025-08-20 Initial commit for sensor board firmware
2025-08-23 Convert ToF sensor reading to centimeters
2025-08-24 Update the interface to communicate with the sensor board
2025-08-25 replace color sensor with AS7341. Port libraries from STM32 OLinuxuino
    [main.c, tcs34725.c, tcs34725.h]
2025-09-15 Stabilize the ToF sensors
    [main.c, vl53l1x.c]
2025-09-16 Initial commit for color sensors
